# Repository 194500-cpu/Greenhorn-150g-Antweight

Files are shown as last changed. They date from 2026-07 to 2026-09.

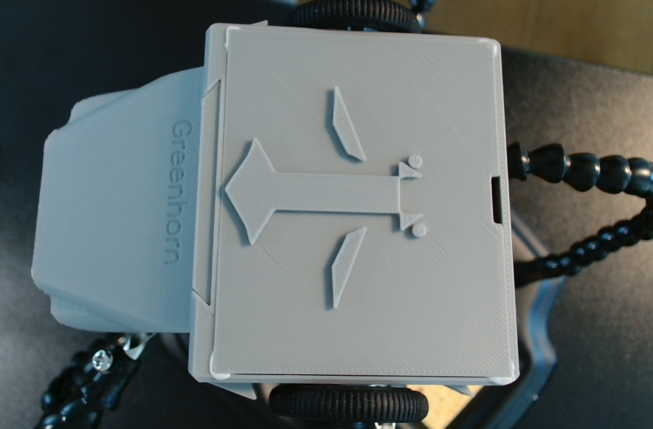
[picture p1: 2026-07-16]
Photos/Topdown1.png

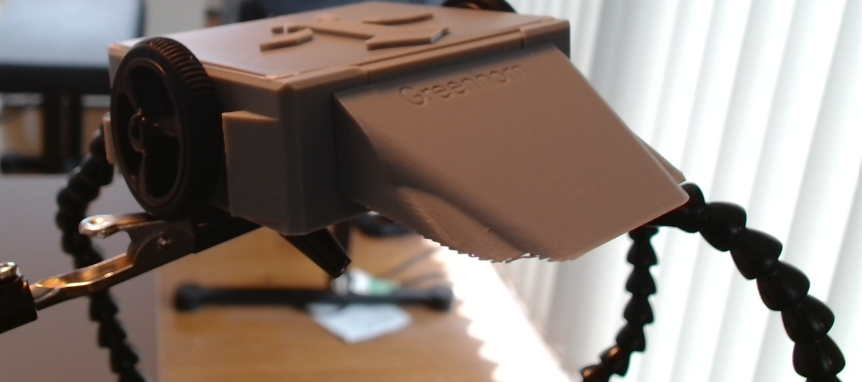
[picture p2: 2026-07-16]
Photos/View1.png

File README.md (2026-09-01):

front

# Greenhorn-150g-Antweight
My 150g antweight wedgebot design (only 3dprinted parts excluding motors/batteries/board).

Key features and design choices I made:
1) The wedge is intetionally not flat at the bottom. It is more of a triangle pointing downwards, in order to have a higher surface clearance.
2) My antweight does NOT use TPU for its wedge, but rather 100% PLA+.  This because the rigid wedge will get under opponents using TPU wedges (90% of opponents).
3) Even when flipped, the bot can still move around.
4) A pointy end helps prevent it from lying on its back (imagine if your bot landed on the back but couldn't self-right -> loss)
5) Finally, the wedge is not flush with the top. The small amount of vertical face helps it to catch onto opponents, not just slide under them.

By combining all these features, I have created a deceptively simple design, which is beginner friendly and competitive.

-Colgation

Demo:
<br>
https://www.youtube.com/watch?v=-txQDBeLUK4

**Step Files and STL files can be found in the repo**

**Important**
Even though I have included the STL files for the antweight bot, I find it better to use Onshape in order to host it to allow modifications and precise parameters. <br>
This is why I havbe included an Onshape document link here: https://cad.onshape.com/documents/7372a678bd67ffef3bf9fe75/w/b756b9b718aa94560d7b57d3/e/aa83c5eda608b85760f218dc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

**Bill of Materials**
-> 2x N20 Motors 6V <br>
-> 2x Polulu Wheels (32mm x 7mm wheels for n20 motors) - https://www.pololu.com/product/1087 <br>
-> A Kakapo V2 board (IF you are confident in ESC/Receiver/Transmitter you can replace this with your own alternative) - https://combatrobotics.co.nz/products/kakapo-2a-v1-2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 <br>
-> 22 AWG Silicone Wire (I recommend stranded) <br>
-> 3dprinted parts in the STL-files folder of this repository (You need to 3d print them, instructions on how are below) <br>
-> A 2S LIHV battery - I used GNB 2S 7.6V 300mAh LiHV Battery 60C <br>
-> 2x M3 10mm screws <br>
-> a male and female JST connector <br>
-> 2 Zipties <br>
-> Blu-tack <br>

**3d Printer Settings**

USE PLA+ FILAMENT, AS IT IS FAR LESS BRITTLE THAN PLA

-> Nozzle Temperature: 220 'C <br>
-> Bed Temperature: 60 'C<br>
-> Print Speeds <br>
Initial layer: 50mm/s <br>
Outer wall: 200mm/s<br>
Inner wall: 300mm/s<br>
-> Layer height: 0.2mm<br>
-> Line width: 0.4mm<br>
-> Infill density: 15%<br>
-> Infill pattern: Grid<br>
-> Wall count: 2<br>
-> Supports: Standard (Needed for wedge and chassis)<br>

**Assembly**
1) Hammer the wedge into the trapezoid hole using a plastic hammer for a friction fit.
2) Align the Kakapo v2 board with the chassis holes and secure it using two 10mm M3 screws. (If you are not using a Kakapo v2 board, skip to step 5).
3) Solder wires to the two right-most terminals. (Note: Outermost is negative, inner is positive).
4) Repeat this process by soldering wires to the two left-most terminals.
5) Solder a male JST connector's positive wire to BAT and negative wire to the adjacent GND.
6) Solder a female JST connector's positive wire to WEAP and negative wire to the remaining GND.
7) Solder the M1 wire to the first N20 motor's positive tab, and the adjacent wire to its negative tab.
8) Solder the M2 wire to the second N20 motor's positive tab, and the final wire to its negative tab.
9) Press both N20 motors into their slots and secure them with zip-ties through the platform holes.
10) Press the wheels firmly onto the motor shafts.
11) Plug the LIHV battery into the male JST connector.
12) Place a small piece of blu-tack onto each of the four corner chassis columns.
13) Press the cover on.
14) FINISHED!

**Photos and Demo**
<br>
TopDown2
Topdown1
View1

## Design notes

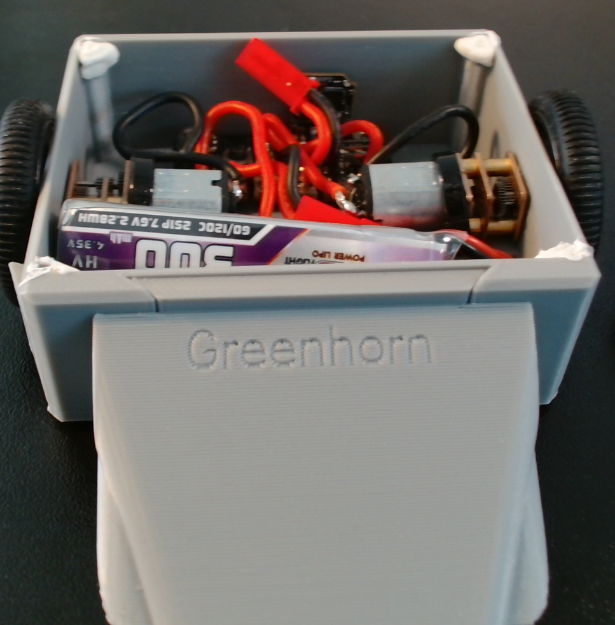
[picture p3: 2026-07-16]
Photos/front.png

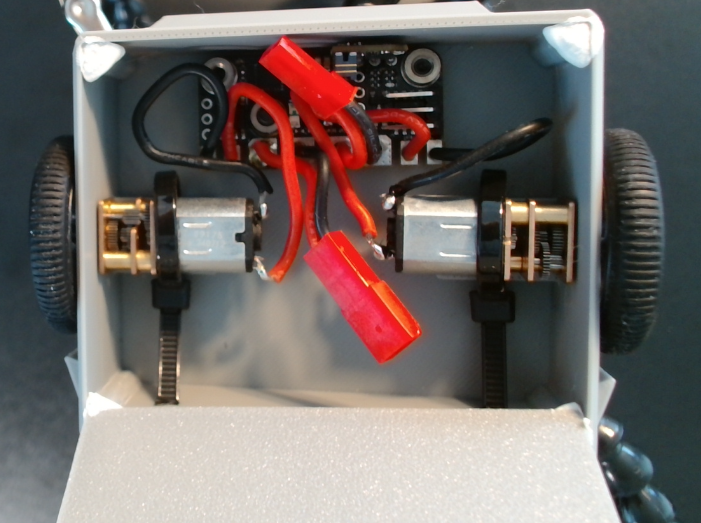
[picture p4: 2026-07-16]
Photos/TopDown2.png

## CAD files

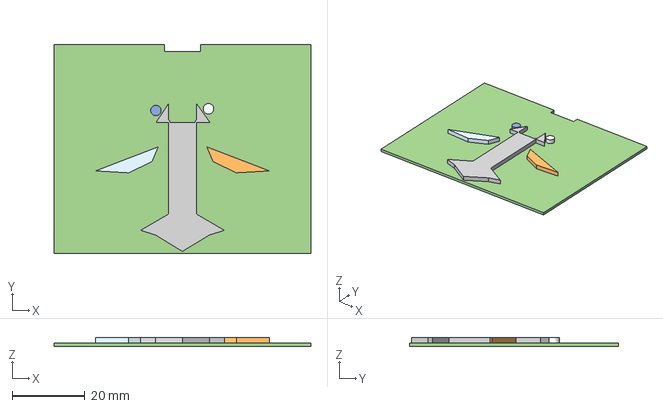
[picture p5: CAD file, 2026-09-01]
cover new design.step
70.5 x 57.4 x 2.42 mm

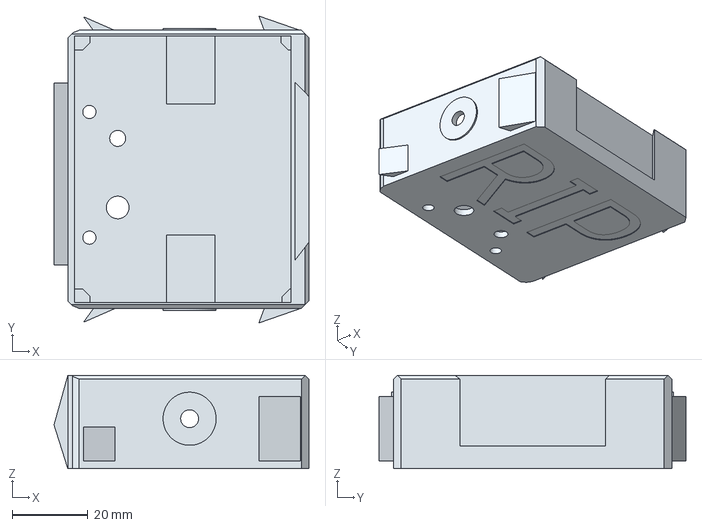
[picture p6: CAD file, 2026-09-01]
Chassis.step
67.5 x 81.3 x 24.7 mm

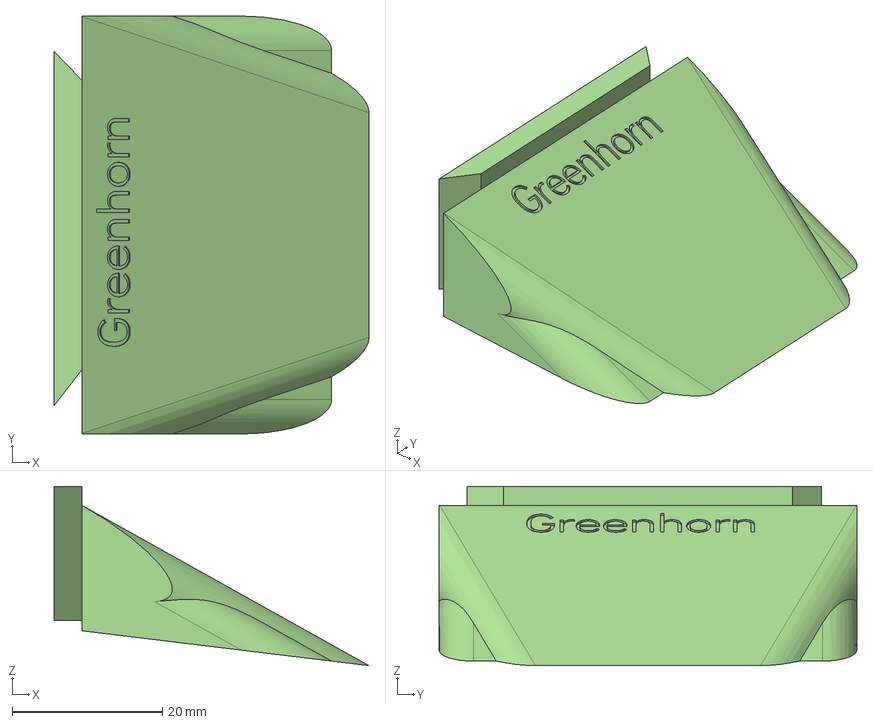
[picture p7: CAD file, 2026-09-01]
wedge.step
42.0 x 55.7 x 23.9 mm

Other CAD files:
STL-Files/cover.3mf
STL-Files/chassis.3mf
STL-Files/wedge.3mf

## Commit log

2026-07-16 Rename Chassis - higher ziptie.3mf to STL-Files/Chassis - higher ziptie.3mf
    [Chassis - higher ziptie.3mf]
2026-07-16 Rename cover new design (1).3mf to STL-files/cover.3mf
    [cover.3mf]
2026-07-16 stl files added
    [chassis.3mf, cover.3mf, wedge.3mf]
2026-07-16 Update README with materials and assembly details
    Added Bill of Materials, 3D Printer Settings, and Assembly instructions to the README.
2026-07-16 Improve formatting in README for clarity
    Updated the Bill of Materials and 3D Printer Settings sections to include line breaks for better readability.
2026-07-16 Revise assembly steps and bill of materials
    Corrected assembly instructions and updated bill of materials for clarity.
2026-09-01 step files
    [Chassis.step, cover new design.step, wedge.step]
